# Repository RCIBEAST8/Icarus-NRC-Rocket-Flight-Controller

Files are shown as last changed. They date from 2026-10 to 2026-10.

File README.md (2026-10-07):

# Icarus - NRC Rocket Flight Controller

This is the avionics for **Icarus**, our entry to the UKSEDS National Rocketry
Championship at Coventry University. I was avionics lead on the team, so what's
in here is the flight computer, the airbrake control code that runs on it, and
the CFD I ran to get the drag numbers that code depends on.

The servo wiggle test running on the bench. It's in `setup()`, so on every power
up the brakes get driven fully open then fully closed before the thing arms. Cheap
way to confirm the servo's actually connected and the linkage is free before you
put it on a rail:

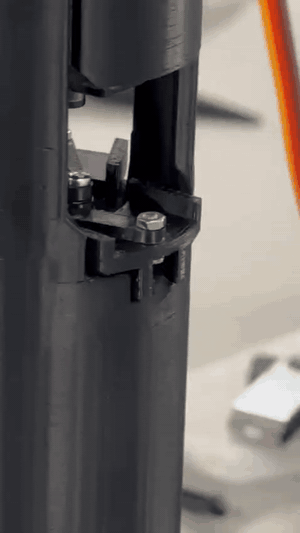
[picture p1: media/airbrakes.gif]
Airbrakes deploying


Full quality version with sound is at
[`media/airbrakes-deployment.mp4`](media/airbrakes-deployment.mp4).

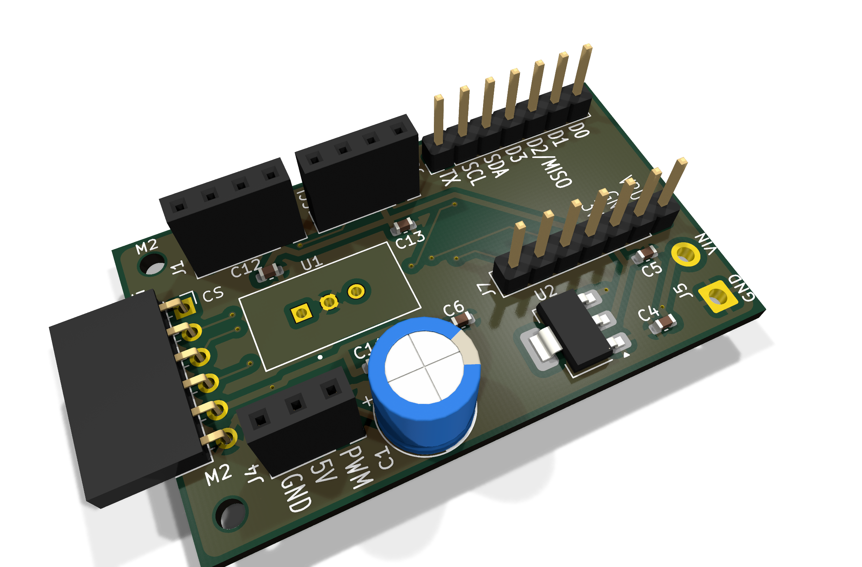
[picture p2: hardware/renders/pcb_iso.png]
Icarus avionics board


## It hasn't flown yet

We withdrew on competition launch day after problems turned up in pre-flight
checks. There's an independent flight test booked to the same parameters.

So everything in this repo is CFD, simulation or bench testing. None of it is
flight validated and it should be read that way.

## The rocket

| | |
|---|---|
| Length | 747.0 mm |
| Body diameter | 50.0 mm |
| Fineness ratio | 14.9 calibers |
| Nose cone | tangent ogive, 117.5 mm (2.35 cal) |
| Fins | 3 at 30 / 150 / 270 deg, 55.0 mm semi-span |
| Airbrakes | 3 blades at 90 / 210 / 330 deg, 12.7 mm proud when deployed |
| Wetted area | 0.1330 m^2 |
| Mass wet / dry | 0.789 kg / 0.7293 kg |
| Motor | AeroTech G78G-7, 109.9 Ns, 1.4 s burn |
| Recovery | separate EggTimer Apogee altimeter |
| Predicted apogee | 563-614 m across the saved OpenRocket runs, 122-125 m/s |

We pull the motor's ejection charge before flight. Recovery runs entirely off a
separate EggTimer Apogee board, so nothing in this repo can drop the parachute
and nothing in this repo can stop it dropping either. That was deliberate. I
didn't want the thing I wrote to be able to lose the rocket.

## What the flight computer does

A Seeed XIAO ESP32-C3 runs a 50 Hz loop, reads an ICM-20948 IMU and a BMP390
barometer, works out altitude and vertical velocity, and drives one servo that
sets how far the airbrakes are out. The point is to hit a target apogee by
dumping the extra energy as drag instead of coasting past it.

Every 20 ms cycle, once the motor's done burning, it:

1. sweeps 41 candidate drag coefficients between `CDClean` and `CDMax`
2. predicts what apogee each one gets you
3. picks whichever lands nearest the 560 m target, with overshoot punished 1.25x
   harder than undershoot (you can always add more drag later, you can never
   take it back)
4. maps that Cd to a servo angle, limited to 3 deg per step

The apogee prediction is a closed form solution rather than a numerical
integration. It comes from `m*dv/dt = -mg - 0.5*rho*Cd*A*v^2`, swapping time for
height, which gives:

```
h = (1/2k) * ln(1 + k*v0^2/g)      where k = rho*Cd*A/(2m)
```

I solve it twice, second pass with the density corrected for the altitude the
first pass says it's going to reach.

That choice matters on this chip. The ESP32-C3 has no hardware FPU, so every
float op is emulated in software. Doing 41 Euler integrations at 50 Hz was never
going to fit. Evaluating a log 41 times does.

### Being honest about the real-time side

This is soft real-time. The loop is a polled timer check inside `loop()`, not a
timer ISR and not a released RTOS task. I have not measured a worst case
execution time and there's no deadline miss detection. SD writes go through a
FreeRTOS queue so card latency can't stall the loop, but that's mitigation, not
a guarantee. I'd rather say that than pretend otherwise.

## Where the drag numbers come from

The controller is only as good as the drag model behind it, so I measured both
ends of it instead of guessing. Two OpenFOAM cases, same mesh and same reference
conditions, only difference being whether the brakes are out:

| Config | Case | Mean Cd | Constant in the firmware |
|---|---|---|---|
| brakes retracted | `cfd/clean/` | 0.472380 | `CDClean = 0.4724` |
| brakes deployed | `cfd/deployed/` | 0.877589 | `CDMax = 0.8776` |

Same mesh, same everything, brakes stowed and brakes out. Rail buttons are on
this side so you can see they're in both, the blades are the only thing that
changes between the two runs:

**Brakes stowed** (`cfd/clean`, Cd 0.4724)

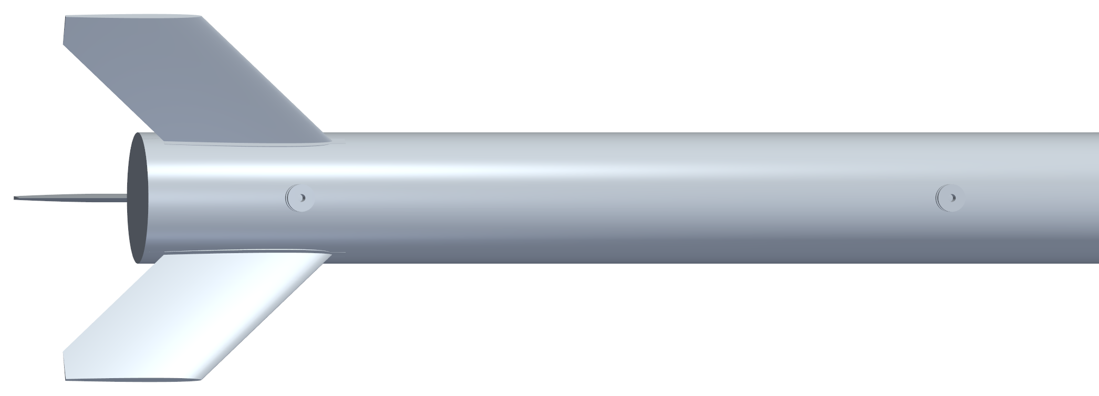
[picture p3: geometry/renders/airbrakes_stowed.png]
Airbrakes stowed


**Brakes deployed** (`cfd/deployed`, Cd 0.8776)

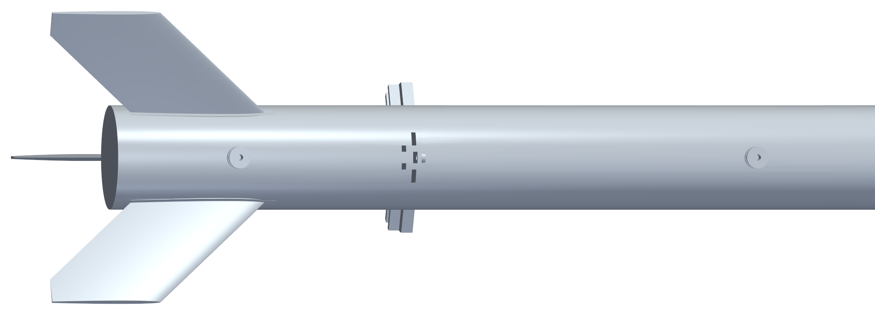
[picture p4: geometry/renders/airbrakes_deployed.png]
Airbrakes deployed


Putting the brakes out is worth 86% more drag. Both numbers are referenced to
the body cross section, `Aref = 0.0019635 m^2` (r = 25 mm), which is the same
value hardcoded in the firmware. That's on purpose, so the CFD and the onboard
prediction can't drift apart.

One thing that catches people out: the total projected frontal area with the
brakes deployed (body plus blades plus fins plus rail buttons) is about
0.00340 m^2, roughly 1.73x the reference area. That's a property of the shape,
not a reference area, and it isn't what any Cd in here is referenced to. Multiply
my coefficients by it and you'll overstate drag by 73%.

## What's in here

`firmware/` has the flight code and a software in the loop sim harness.
`hardware/` has renders of the board. `cfd/` has the OpenFOAM case setups, the
drag results for both configs and renders of the flow field. `simulation/` has
the OpenRocket model, the motor curve and a MATLAB script for reading flight
logs. `geometry/` has the STL the CFD was run against. `media/` has the bench
test footage.

### On the board

Renders only. I'm not publishing the schematic, layout, netlist or anything you
could send to a fab. The board's there to show what I built, not to be copied.
Ask me if you need more than that.

The customer payload we carried for the competition isn't in here at all. That
spec isn't mine to publish.

## Attribution

See [NOTICE.md](NOTICE.md). Icarus was a team vehicle and this repo only covers
my part of it.

There's no licence file, which means all rights reserved. Ask before reusing
anything.

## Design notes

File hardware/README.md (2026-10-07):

# Hardware

Isometric

Renders only. The schematic, layout, netlist and fabrication outputs (Gerbers,
drill files, pick and place) are deliberately not published and are blocked in
`.gitignore`. The board's here to show what I built, not for anyone to send off
to a fab. Ask me if you need more detail than this.

It's a 50.0 x 30.0 mm two layer board. The XIAO ESP32-C3 sits at `U1` and
basically everything else on there exists to power it, break its buses out, and
keep it alive while a servo shares the same supply.

| Ref | What it is |
|---|---|
| `U1` | Seeed XIAO ESP32-C3 module footprint |
| `U2` | SOT-223 linear regulator, with `C4` / `C5` either side of it |
| `C1` | bulk electrolytic, sat right next to the servo header |
| `J1`, `J2` | two I2C breakouts (SCL, SDA, 3V3, GND) for the IMU and the baro |
| `J3` | SPI header for the microSD, with CS broken out |
| `J4` | servo (GND, 5V, PWM) |
| `J7`, `J8` | XIAO headers, VBUS/3V3/GND one side, D0-D3/TX/SDA/SCL the other |
| `VIN`, `GND` | power in |
| `M2` x2 | mounting holes |

The bulk cap next to `J4` is there on purpose. A servo under stall load pulls
current in sharp bursts and without local bulk capacitance those transients drag
the rail down far enough to brown out the microcontroller mid flight. The IMU and
baro also get their own separate I2C headers rather than being daisy chained, so
each one gets a short run.

There are four renders in `renders/`: an isometric and a flat top down
(`pcb_iso.png`, `pcb_top.png`), plus the same two from underneath
(`pcb_iso_bottom.png`, `pcb_bottom.png`). The flat top down is the useful one if
you want to read the silkscreen and follow the routing.

They're generated out of the KiCad 10 project with `kicad-cli pcb render`. `U1`
and `J3` show up as plain outlines because those footprints don't have 3D models
attached, so the XIAO itself isn't shown sitting in its socket.

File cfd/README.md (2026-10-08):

# CFD

Two OpenFOAM cases over the same mesh and the same reference conditions. The only
thing that changes between them is whether the airbrakes are out. These two runs
are where the controller's drag model comes from.

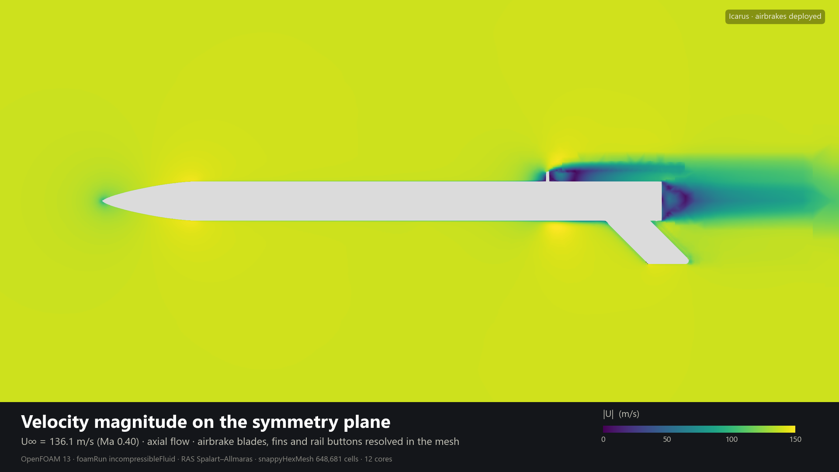
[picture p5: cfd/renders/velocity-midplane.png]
Velocity magnitude on the symmetry plane, airbrakes deployed


| Case | Brakes | Mean Cd | Firmware constant |
|---|---|---|---|
| `clean/` | retracted | 0.472380 | `CDClean = 0.4724` |
| `deployed/` | deployed | 0.877589 | `CDMax = 0.8776` |

86% more drag with the brakes out. Mean Cd is averaged over 0.025-0.050 s, after
the force history has settled down. `rangeCD.dat` in each case has the standard
deviation and the min/max over that window if you want to see how steady it was.

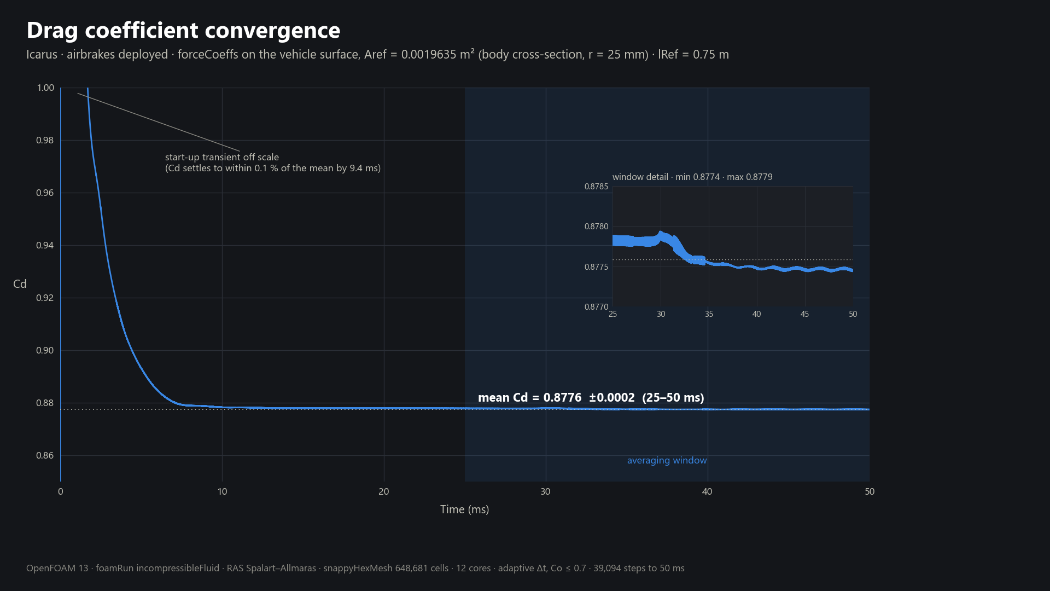
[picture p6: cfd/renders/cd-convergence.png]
Drag coefficient convergence, deployed case


Cd is inside 0.1% of its own mean by 9.4 ms and the whole averaging window fits in
±0.0002, so the number isn't sensitive to where I put the window.

Every picture on this page is the deployed run at the final time, 0.05 s.

## Setup

| | |
|---|---|
| Solver | OpenFOAM 13, `foamRun` |
| Turbulence | RAS, Spalart-Allmaras |
| Freestream | 136.1 m/s, which is Mach 0.40 |
| Density | 1.225 kg/m^3 |
| Kinematic viscosity | 1.5e-5 m^2/s |
| Reynolds number | about 6.8e6 on lRef = 0.75 m |
| Reference area | 0.0019635 m^2, body cross section at r = 25 mm |
| Reference length | 0.75 m |
| Time stepping | adjustable, max Courant 0.7, ends at 0.05 s |

`Aref` is the body cross section. It is not the total projected frontal area of
the deployed config (that's about 0.00340 m^2, 1.73x bigger). The firmware uses
the same 0.0019635, so the CFD and what the rocket thinks are always the same
number.

## What the flow looks like

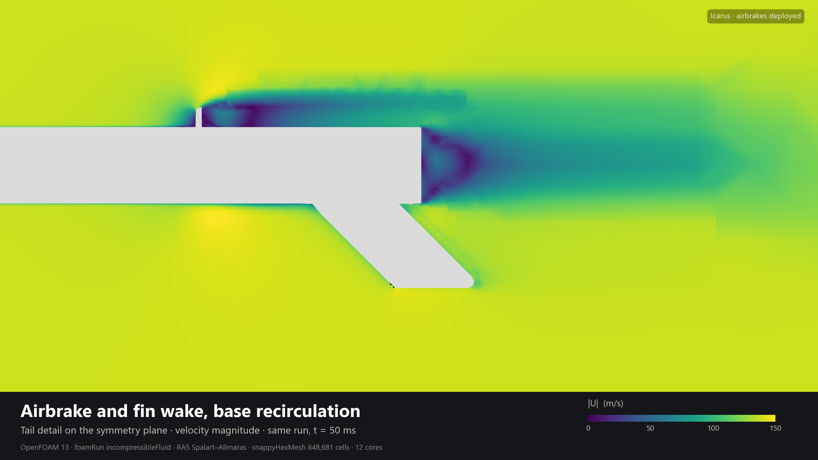
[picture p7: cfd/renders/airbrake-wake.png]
Airbrake and fin wake, base recirculation


The blades sit just ahead of the fins and throw a thick low speed wake straight
down the fin span. The flat base is doing its own share behind that, with the
recirculation sitting in the middle of it.

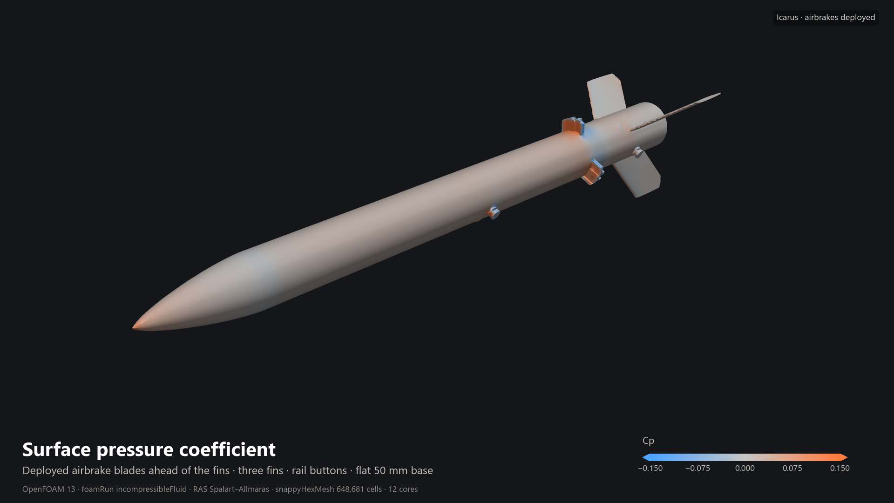
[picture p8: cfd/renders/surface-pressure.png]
Surface pressure coefficient


Cp on the skin. High pressure on the nose and on the leading face of each blade,
suction immediately behind them, and the rail buttons showing up as their own
little pressure spots. The scale is clipped at ±0.15 so the nose saturates, real
stagnation Cp there is about 1.

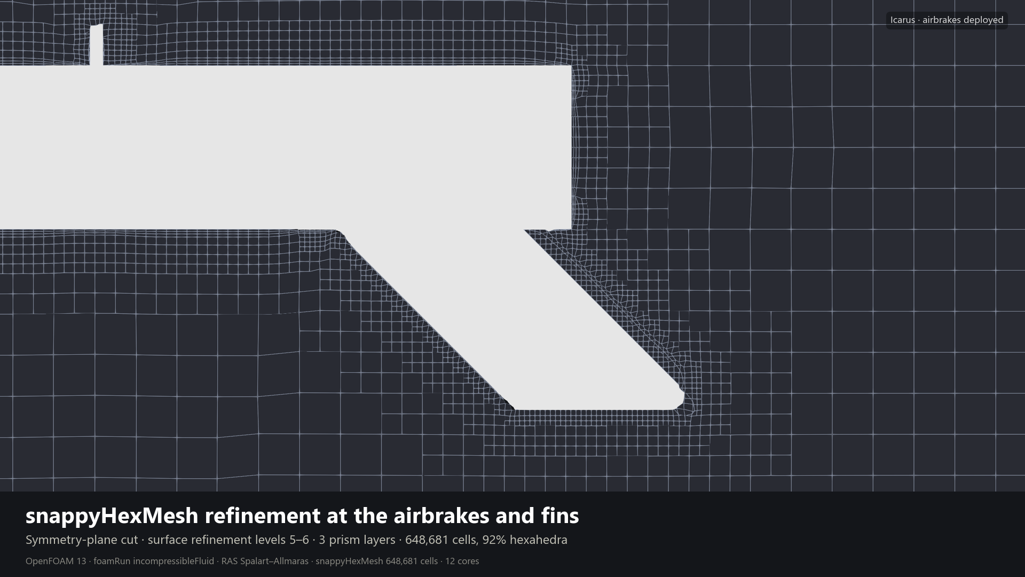
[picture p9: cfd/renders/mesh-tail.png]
snappyHexMesh refinement at the airbrakes and fins


The mesh around the tail. Surface refinement levels 5-6, 3 prism layers, 648,681
cells with 92% of them hexahedra. `checkMesh` flagged 8 highly skewed faces, so
it isn't a clean pass.

## Where these numbers are weak

Worth being straight about, because it tells you how far to trust them.

The solver is incompressible and I'm running it at Mach 0.40. The usual rule of
thumb is incompressible holds to about Mach 0.3. At 0.40 the real density
variation over the vehicle is something like 8%, so treat these as a solid
engineering estimate rather than a converged compressible answer.

The airbrake blades are modelled as detached plates. In the mesh the radius jumps
from 25.0 to 33.4 mm with an 8.4 mm gap, and there's no linkage or slot geometry
in there at all.

The back end is a flat 50 mm disc. No nozzle, no boat tail. Base drag is doing
real work in the clean number because of that.

Axial flow only, one angle of attack. No yaw or pitch sweep.

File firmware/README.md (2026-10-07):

# Firmware

`XIAO_ESP32-C3_CODE.ino` is the flight code. `Xiao_sim_test.ino` is the same
controller wired to a synthetic flight so I can test it without burning a motor.

## Hardware it runs on

Seeed XIAO ESP32-C3 (RV32IMC). No hardware FPU, so every float operation is
emulated in software. That's the single biggest constraint on what fits in the
loop budget and it's why the apogee predictor is a closed form solution.

| Part | Bus | Notes |
|---|---|---|
| ICM-20948 | I2C | 9 axis IMU |
| BMP390 | I2C | barometer, this is the primary altitude source |
| microSD | SPI | logging, behind a FreeRTOS queue |
| airbrake servo | PWM | 0-126 deg, 126 is a mechanical limit on the linkage |

Loop runs at 20 ms (50 Hz). Barometric velocity is filtered down to 10 Hz on
purpose, slower than the loop, so the estimator isn't chasing sensor noise.

MISO isn't on the usual pin, because of boot state issues on the XIAO.

## States

`PAD_IDLE` -> `ASCENT` -> `DESCENT` -> `LANDED`

Launch detect fires on integrated IMU distance >= 1.0 m or altitude >= 50 m AGL.
That pad integration (`currentvelocity`) is only used to spot the launch and to
seed the in-flight estimate, it gets thrown away after that because it drifts.

In flight the accelerometer propagates velocity every 20 ms tick and the
barometer corrects it, pulling the estimate 35% of the way toward the alpha-beta
baro velocity each 10 Hz update. During the burn that correction is switched off
completely, so for the first 1.4 s it's running on the accelerometer alone.

Apogee detect needs peak altitude above 50 m first, then fires on fused velocity
< -2.0 m/s or 5 falling samples in a row. Landing detect wants to be below 25 m
AGL with altitude stable within 3 m and acceleration within 1.5 m/s^2 of 1 g,
held for 5 seconds.

Brakes stay stowed until burn time + 0.1 s, then the controller arms. That delay
is there to stop the servo straining against itself. Three seconds after apogee
they get driven fully open to add drag on the way down.

## Constants worth knowing

| Constant | Value | What it is |
|---|---|---|
| `alpha` / `beta` | 0.4 / 0.05 | alpha-beta filter gains on baro altitude |
| `BARO_TRUST` | 0.35 | how much of the baro/inertial gap gets corrected each tick |
| `area` | 0.0019635 m^2 | CFD reference area, has to match the CFD |
| `CDClean` / `CDMax` | 0.4724 / 0.8776 | straight out of `cfd/clean` and `cfd/deployed` |
| `apogeeTgt` | 560 m | target apogee (about 1840 ft) |
| `overshootPenalty` | 1.25 | makes the controller prefer undershooting |
| `MPC_CANDIDATES` | 41 | how many drag values it tries per cycle |

`padMass` is the wet mass at 0.789 kg, `dryMass` is 0.7293 kg. Through the burn
the mass is interpolated linearly between the two on elapsed time, then held at
dry mass after burnout. A straight line isn't the real burn profile, but the burn
is 1.4 s and the MPC doesn't arm until 0.1 s after it, so in practice the
controller only ever sees dry mass anyway.

## Real-time classification

Soft real-time. It's a polled periodic trigger in `loop()`, not a timer ISR and
not a released RTOS task. No measured worst case execution time, no deadline miss
detection. SD writes are queued so they can't stall the loop.

Guards that are in there: density clamped to 0.6-1.4 kg/m^3, velocity clamped to
-150 to 200 m/s, barometric altitude rejected outside -500 to 10000 m, a divide
by zero guard on the drag term, servo rate limiting and a 5 degree deadband.

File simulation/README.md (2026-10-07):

# Simulation

`NRC_Rocket.ork` is the OpenRocket model, `AeroTech_G78G.eng` is the motor curve,
and `ICARUS_Flight_Data_Logger_v2.m` is the MATLAB script I use to read flight
and sim logs back.

## What OpenRocket predicts

The model holds several saved runs. They land between 562.7 m and 613.7 m
apogee, with max velocity between 121.6 and 124.5 m/s.

Those are clean numbers, brakes stowed the whole way up. The flight code targets
560 m, which sits under every run here, so the controller always has something to
trim off. The slowest run only clears the target by about 3 m though, so that's
the case worth re-running when the model gets updated.

## Motor, AeroTech G78G-7

| | |
|---|---|
| Total impulse | 109.9 Ns |
| Peak / average thrust | 101.9 N / 78 N |
| Burn time | 1.4 s |
| Propellant / total mass | 59.7 g / 125.0 g |
| Size | 29 x 146 mm |
| Delay | 7 s |

Don't swap in the ThrustCurve "G78G/L" RASP file. It's a different variant
(133.2 Ns, 1.7 s burn, 128 mm long) and it does not match this motor. It'll run
fine and quietly give you the wrong trajectory, which is worse than it failing.
The curve in here is modelled off published AeroTech / Apogee data and hits total
impulse, peak and mean to inside 0.1%.

The 7 second ejection delay doesn't get used. We take the ejection charge out
before flight and recovery is triggered by a separate EggTimer Apogee altimeter,
so the flight code ignores motor driven deployment completely.

## Reading logs back

`ICARUS_Flight_Data_Logger_v2.m` pulls the SD log in and plots altitude,
velocity, servo angle, the Cd the controller asked for and what apogee it was
predicting at the time. v2 works out the column count from the header instead of
hardcoding it, so it takes both the 18 column real flight log and the 20 column
sim log (the sim one carries `TrueAlt` and `TrueVel` ground truth out of
`Xiao_sim_test`).

Set `CFG.file` to point it at something, or just drop it in a folder full of CSVs
and it grabs the newest one.

Check `CFG.targetApogee` before you read anything into a plot. It defaults to
530 m and the flight firmware now targets 560 m, so if they don't match the error
traces will look wrong.

One that's easy to get backwards: 126 degrees is stowed (minimum drag) and 0 is
fully open (maximum drag).

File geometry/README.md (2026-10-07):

# Geometry

`SRocketMesh.stl` is the deployed airbrake outer skin and it's the exact surface
the CFD in [`../cfd/`](../cfd/) ran against.

24,810 triangles, roughly 3.3 mm mean edge length, one `zone0` solid, units in
metres.

## The two configurations

Both meshes rendered from the same camera, viewed from the side the rail buttons
are on. Brakes stowed first, then deployed.

Airbrakes stowed

Airbrakes deployed

Closer in on the blade station, same pair:

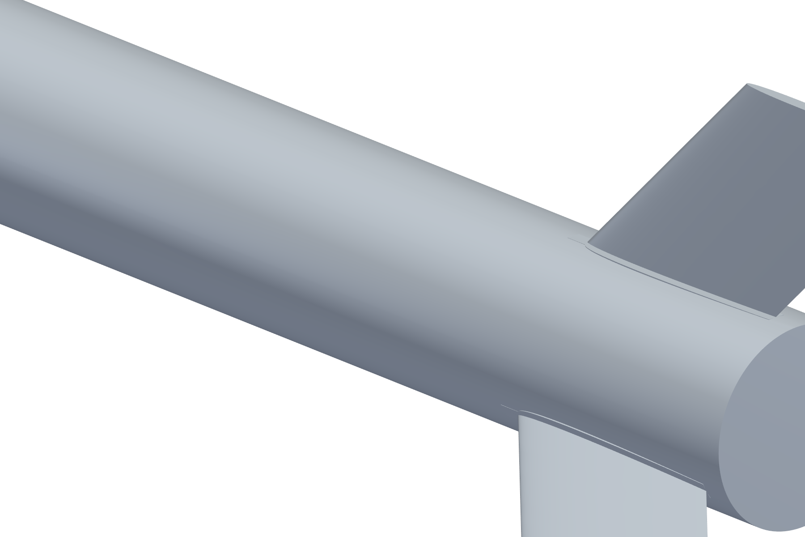
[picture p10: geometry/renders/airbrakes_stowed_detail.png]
Airbrakes stowed, detail


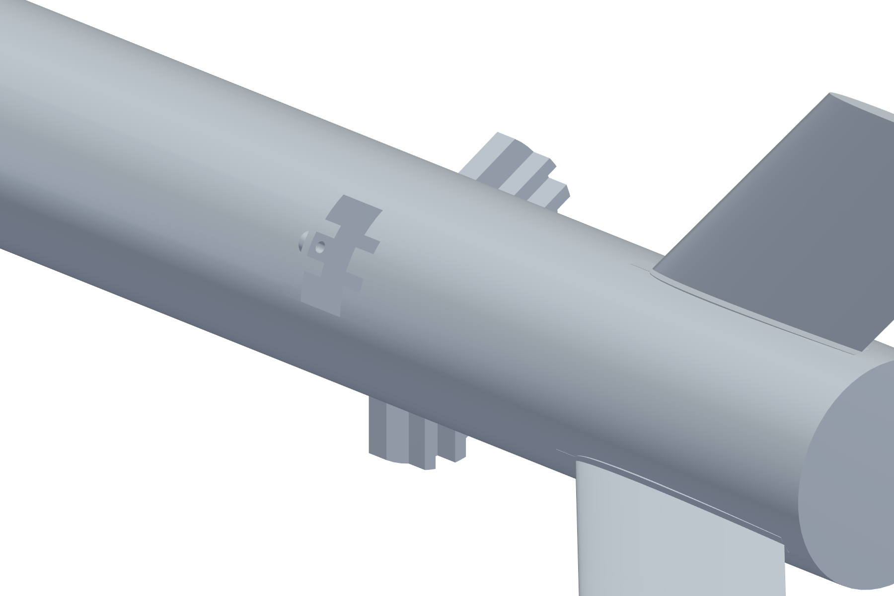
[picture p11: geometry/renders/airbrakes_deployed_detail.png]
Airbrakes deployed, detail


I checked the two meshes actually match everywhere else before running them.
Walking the radius along the body they're identical, including the rail buttons
at r = 31.93 mm, and the only station that differs is x = -160 to -120 mm where
the deployed mesh goes out to r = 37.69 mm and the clean one stays at 25.00 mm.
So the difference in Cd between the two runs is the airbrakes and nothing else.

## Measured dimensions

I took these off the STL itself rather than out of CAD, so they're what the
solver actually saw rather than what the model was supposed to be.

| | |
|---|---|
| Overall length | 747.0 mm |
| Body diameter | 50.0 mm (r = 25.0) |
| Fineness ratio | 14.9 calibers |
| Nose cone | tangent ogive, 117.5 mm (2.35 cal), fits to about 1 mm |
| Parallel body | x = 117.5 to 640.5 mm (523 mm) |
| Fins | 3, at 30 / 150 / 270 deg |
| Fin root / tip chord | 106.5 mm / 53.8 mm |
| Fin semi-span | 55.0 mm from the wall, 160 mm tip to tip (3.2 cal) |
| Fin LE sweep | about 44.5 deg |
| Fin section | tapered, 3.25 mm max thickness, 0.6 mm at the TE |
| Airbrakes | 3 blades at 90 / 210 / 330 deg, interleaved between the fins |
| Blade station | x = 564.5-575.0 mm, 10.5 mm streamwise |
| Blade arc | 38.2 deg each, so 114.6 deg total, about 32% of the circumference |
| Blade deployment | outer face at r = 37.7 mm, 12.7 mm proud of the body |
| Rail buttons | 2 at 210 deg, 10.5 mm long, 6.9 mm proud, x = 398 and 649 mm |
| Wetted area | 0.1330 m^2 |
| Enclosed volume | 1.31 L |

## Two different areas, don't mix them

There are two frontal areas floating around for this rocket and they are not
interchangeable.

The body reference area is 0.0019635 m^2. That's what every Cd in this repo is
referenced to and it's the `area` constant in the flight firmware.

The total projected frontal area with the brakes out is about 0.00340 m^2. That's
body plus blades plus fins plus rail buttons and it's 1.73x the first number.
It's a description of the shape, not a reference area. Multiply my coefficients
by it and you overstate drag by 73%.

## Simplifications in this mesh

The airbrake blades are detached plates. The radius jumps 25.0 to 33.4 mm with an
8.4 mm void and there's no linkage or slot modelled.

The aft end is a flat 50 mm disc, no nozzle and no boat tail, so base drag is
carrying real weight in the clean coefficient.

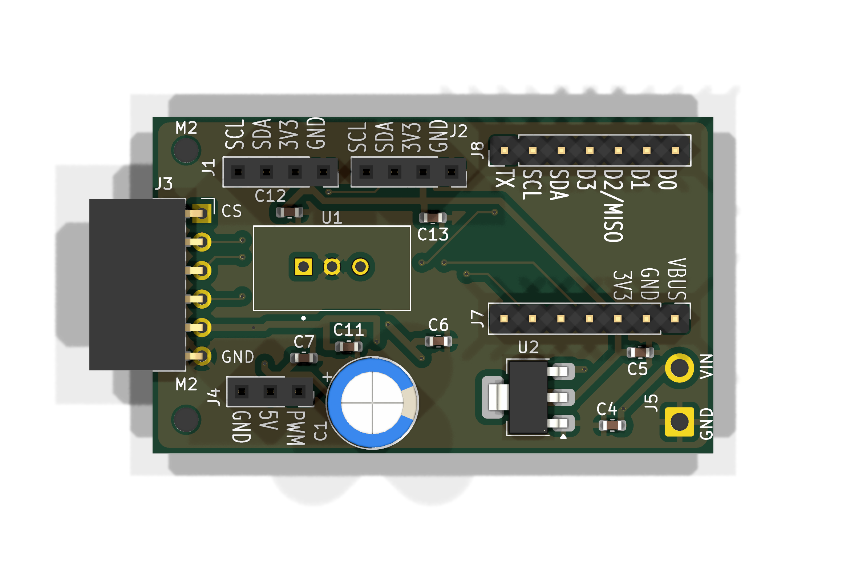
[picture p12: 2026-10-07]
hardware/renders/pcb_top.png

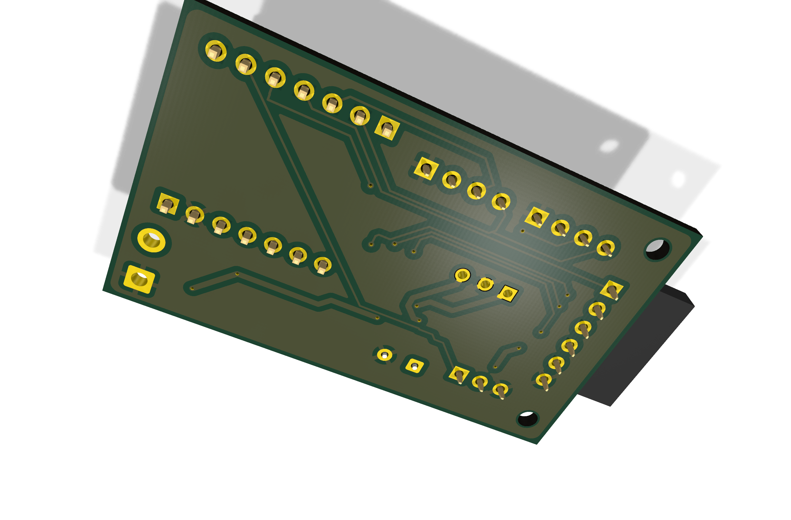
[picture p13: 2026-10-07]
hardware/renders/pcb_iso_bottom.png

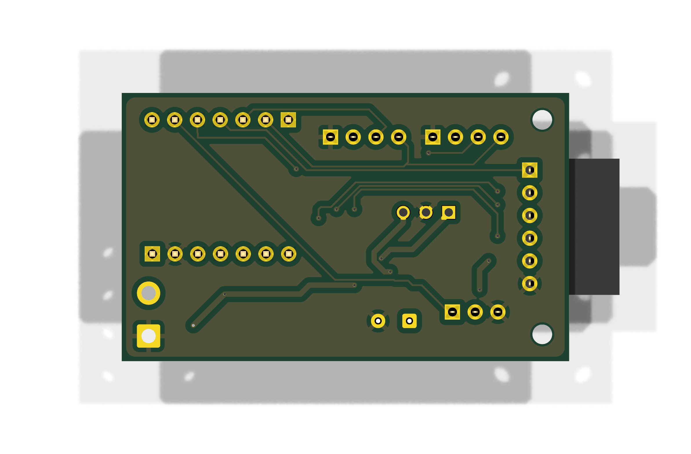
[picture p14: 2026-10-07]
hardware/renders/pcb_bottom.png

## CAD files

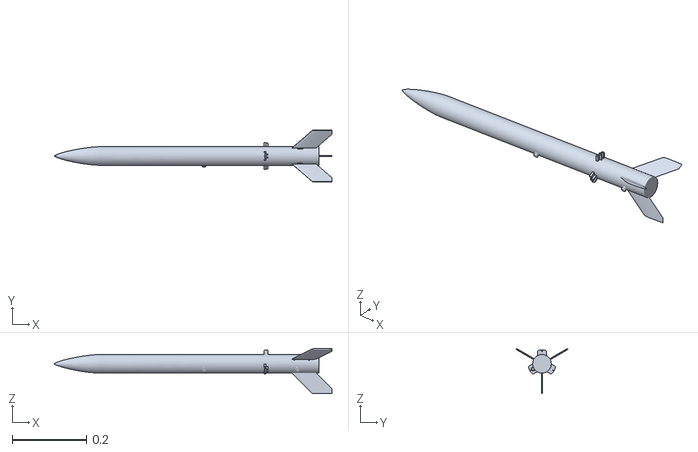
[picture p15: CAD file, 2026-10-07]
geometry/SRocketMesh.stl
0.747 x 0.14 x 0.121

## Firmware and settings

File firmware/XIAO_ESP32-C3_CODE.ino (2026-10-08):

// for xiao esp32-c3  (no FPU so thats why there is "f" on most values)
// Icarus rocket
// mpc controller

//code breakdown
//sensor logger for icm-20948 and bmp390 sensors which writes data onto an sd card in CSV format so easy to graph.
//active aero sim to slow down the rocket to reach target apogee. active aero sim controls servo motor for the airbrakes.

//libs
#include <SPI.h>
#include <SD.h>
#include <Wire.h>
#include <Adafruit_Sensor.h>
#include <Adafruit_BMP3XX.h>
#include <Adafruit_ICM20X.h>
#include <Adafruit_ICM20948.h>
#include <ESP32Servo.h>


#define SEALEVELPRESSURE_PA (101325.0) //sea level in pascals
#define BMP_PRESSURE_IS_PA 1 // 1 means pa // 0 means hpa

// SPI linking 
const int chipSelect = D3;
const int SD_SCK  = D8;
const int SD_MISO = D2;  // not the normal MISO pin, the default one messes with boot on the xiao and drops it into sleep states
const int SD_MOSI = D10;

//sensor objects
Adafruit_BMP3XX bmp;
Adafruit_ICM20948 icm;
Servo myservo;

//  data logging object
File dataFile;

// creating a ram buffer to compile before writing // 256bytes x 100 depth = 25.6KB of SRAM out of 400 total
QueueHandle_t sdQueue;
TaskHandle_t sdTaskHandle;
#define LOG_BUF_LEN   256     //ram buffer 
#define LOG_QUEUE_LEN 100     //queue depth
char logBuffer[LOG_BUF_LEN];
bool loggingEnabled = true;

// better than delays logs at 50hz (20ms)
unsigned long previousMicros = 0;
const unsigned long INTERVAL_US = 20000UL; //20ms
unsigned long loopDtUs = 0;

//rocket airbreak master controller
enum FlightState
{
  PAD_IDLE,
  ASCENT,
  DESCENT,
  LANDED
};
FlightState currentState = PAD_IDLE;

//altitude variables
float groundAltitude = 0.0;
float currentAltitude = 0.0;
float previousAltitude = 0.0;
unsigned long previousTime = 0;

// distance and velocity tracking for code starter. code is gonna kick in a 1m as the rocket will reach that after 140ms with roughly 101m/s (acceleration) off launch.
//starting code
float currentvelocity = 0.0;     // used only on pad not in air (drifts values alot)
float barovelocity = 0.0;
float distancetravelled = 0.0;
float predictedVel = 0.0;
float baroAccel = 0.0;
float alpha = 0.4;                // controls how strongly the barometer measurements corrects velocity estimates // higher the number higher the noise but faster tracking
float beta = 0.05;                // similar to above but extremely noise so set very low 
float fusedVelocity = 0.0;        // the velocity the mpc uses as the baro is filtered at 10hz in code even though the sensor runs at 50hz, im making it purposely lower
const float BARO_TRUST = 0.35;    // how hard each baro tick corrects the fusion // 0.35 means 35% of the gap on every tick basically enough to stop accelerometer drift

//sanity clamps for BMP
const float RHO_MIN = 0.6;
const float RHO_MAX = 1.4;
const float VEL_MIN = -150.0;
const float VEL_MAX = 200.0; // real max vel is ~116m/s so 85m/s of headroom 

//backup apogee detection
int fallingCount = 0; //back up incase velocity estimate is wack
float peakAltitude = 0.0; // logs highest altitude reach at all times

//landing detection and health check
unsigned long stillSince =0;
volatile bool closeRequested = false;
unsigned int droppedLogs = 0;
unsigned int missedBaro = 0;

//referance altitude and brands for landing detector
float landingRefAlt = 0.0;
const float LANDING_ALT_MAX  = 25.0;   // max altitude from pad altitude which landing could happen at. pad is roughly 103m from sealevel so max would be +128m and -78m more than big enough headroom
const float LANDING_ALT_BAND = 3.0;    // altitude must not move more than this
const float LANDING_ACC_BAND = 1.5;    // |a| must be within this of 1g

// REAL TIME MASS CALC
unsigned long launchTime = 0;           // total launch time from burn start
float dryMass = 0.7293;                 // DRY MASS WEIGHT
float padMass = 0.789;                  // WET MASS 
float currentMass = padMass;
float burnTime = 1.4;                   //1.4s rocket burn // G78G-7 aerotech rocket motor 

//servo controller
int currentServoAngle = 126;    // tracks servo degrees
const int SERVO_MIN = 0;        // hard lower limit // open = max drag
const int SERVO_MAX = 126;      // hard upper limit // closed = least drag
const int SERVO_STEP = 3;       // maximum degrees per step
const int SERVO_DEADBAND = 5;   // ignores any movements under 5 degrees 

//mpc varibles 
float area = 0.0019635;                  // cfd referenace area 
float rho = 1.225;                       // density of air (1.225kg/m^3)
float CDClean = 0.4724;                  // airbrakes retracted //validated by my CFD
float CDMax   = 0.8776;                  // airbrakes deployed  //validated by my CFD
float CD = CDClean;                      // mpc starts clean each run
int apogeeTgt = 560;                     //apoge target in metres (560m = 1837 feet) (580m = 1902 feet) (600m = 1968 feet)
const float overshootPenalty = 1.25;     // tells the mpc to aim for slight undershoot rather than extreme overshoot
const float MPC_ARM_MARGIN_S = 0.1;      // 0.1s delay before servo is aloud to move after burn phase so it doesnt strain itself, might change to 0.3seconds

//apogee airbrake controller
const unsigned long AIRBRAKE_DESCENT_DELAY_MS = 3000UL; // 3 second delay after apogee to max airbrakes
unsigned long apogeeTime = 0;
bool brakesDeployed = false; // check airbrake state

// MPC stuff
#define MPC_CANDIDATES 41  // amount of simsulations
float bestApogee = 0.0;    //what the winning candidate predicted 

// accelerometer scale correction 
float accelScale = 1.0f;

//tells compiler to run the SD background tasks
void logToSDTask(void *pvParameters);

// makes sure everything is done in pascals 
float pressurePa()
{
#if BMP_PRESSURE_IS_PA
  return bmp.pressure;
#else
  return bmp.pressure * 100.0;
#endif
}

//altitude checker
float altitudeFromPa()
{
  return 44330.0f * (1.0f - powf(pressurePa() / (float)SEALEVELPRESSURE_PA, 0.1903f)); //barometric formula but inverted for height
}

// density checker
float airDensity()
{
  return pressurePa() / (287.05f * (bmp.temperature + 273.15f));  // ideal gas law rearranged 
}

//                                       apogee predictor                                            // 

// sim predicts what do with the brakes based on the logic of if i slammed the brakes now and coast what would my apogee be
// sim comes from:        m·dv/dt = -mg - ½·ρ·Cd·A·v²       which goes to       v·dv/dh = -g - k·v²        where k = ρ·Cd·A/(2m) where time is swapped for height using   v·dv/dh = dv/dt
float predictApogee(float cdSim, float alt0, float v0, float mass)
{
  if (v0 <= 0.0f) return alt0;                                            // checks how much the rocket will climb at current speed, (also techincally kills the sim at apogee where velocity becomes negative along Y axis)
  float k = (rho * cdSim * area) / (2.0f * mass);                         // bundles the whole drag setup into one number
  if (k < 1e-9f) return alt0;                                             // divide-by-zero guard (would of put a NaN but it woulda killed it)
  float h = (1.0f / (2.0f * k)) * logf(1.0f + (k * v0 * v0) / 9.81f);     // sim output (how much higher the rocket will climb until apogee (velcoity =0))
  float rhoMid = rho * (1.0f - (0.5f * h) / 8500.0f);                     // redo sim but with decaying density (air thinner not by much but mayaswell)
  if (rhoMid < RHO_MIN) rhoMid = RHO_MIN;                                 // stops a insane H value given (basically if h was too big it would turn rhoMid negative basically saying neagtive density which means negative drag so bad)

 // redoes the sim part with the new density (more accurate density)
  k = (rhoMid * cdSim * area) / (2.0f * mass); 
  if (k < 1e-9f) return alt0;
  h = (1.0f / (2.0f * k)) * logf(1.0f + (k * v0 * v0) / 9.81f);
  return alt0 + h;                                                        // coast height (h) added to curent altitude (predicted apogee)

}

//                                      main setup                                  //
void setup()
{
  // setting up SD card
  Serial.begin(115200); //115200 baud rate
  Serial.setTxTimeoutMs(0); // doesnt block the loop if not device is attached
  Serial.println("initialising");
  delay (2000); // safety net

  // Creates the queue in RAM and launches the background SD logger.
  //also kills logging if queue crashes so it doesnt kill the entire code
  sdQueue = xQueueCreate(LOG_QUEUE_LEN, sizeof(logBuffer));
  if (sdQueue == NULL)
  {
    Serial.println("QUEUE ALLOCATION FAILED - SD logging disabled");
    loggingEnabled = false;
  }
  xTaskCreate(
    logToSDTask,   //task function
    "SD_Task",     //name
    4096,          //stack size
    NULL,          //parameters
    1,             //priority
    &sdTaskHandle  //handle
  );

  //the xiao needs its own timers allocated before it'll write servos
  ESP32PWM::allocateTimer(0);
  ESP32PWM::allocateTimer(1);
  ESP32PWM::allocateTimer(2);
  ESP32PWM::allocateTimer(3);
  myservo.setPeriodHertz(50);
  myservo.attach(D1, 500, 2400); // servo pin is now D1


  //                    SERVO WIGGLE TEST                                         //
  Serial.println("performing servo wiggle test");
  myservo.write(SERVO_MIN); // 0 Degrees (Fully Open)
  delay(1000);
  myservo.write(SERVO_MAX); // 126 Degrees (Fully Closed)
  delay(1000);
  currentServoAngle = SERVO_MAX; // Ensure logic matches physical state
  Serial.println("Servo test complete now ready to launch");


  //cranking up the speed on i2c bus to 400kHz
  Wire.begin();
  Wire.setClock(400000);

  SPI.begin(SD_SCK, SD_MISO, SD_MOSI, chipSelect); //forcing spi pins

  if (!SD.begin(chipSelect, SPI, 4000000)) // checks SD card is working and kills logging if its fails so doesnt kill code
  {
    Serial.println("SD Card Failed - CONTINUING WITHOUT LOGGING");
    loggingEnabled = false;
  }

  Serial.println("Initializing BMP390 Sensor");
  if (!bmp.begin_I2C())
  {
    Serial.println("BMP390 Failed to initialize");
    while(1) { vTaskDelay(pdMS_TO_TICKS(100)); } //properly block BMP390 if it fail fails (better than yield)
  }


  // built in filtering and oversampling + preflight checker 
  if (!bmp.setTemperatureOversampling(BMP3_OVERSAMPLING_2X)) Serial.println("WARNING: temp OSR rejected");
  if (!bmp.setPressureOversampling(BMP3_OVERSAMPLING_4X))    Serial.println("WARNING: press OSR rejected");
  if (!bmp.setIIRFilterCoeff(BMP3_IIR_FILTER_COEFF_3))       Serial.println("WARNING: IIR coeff rejected");
  if (!bmp.setOutputDataRate(BMP3_ODR_50_HZ))                Serial.println("WARNING: 50Hz ODR REJECTED - oversampling too high");


  // checking ICM-20948 sensor
  Serial.println("initializing TDK INVENSENSE ICM-20948");
  if (!icm.begin_I2C())
  {
    Serial.println("ICM-20948 Failed to initialize");
    while(1) { vTaskDelay(pdMS_TO_TICKS(100)); } // same reason as BMP 390
  }

  icm.setAccelRange(ICM20948_ACCEL_RANGE_16_G);    // sets IMU to +or- 16G / peak G should be 11G
  icm.setGyroRange(ICM20948_GYRO_RANGE_2000_DPS);  //sets IMU to max 2000 degrees of roll per a second

  // read ICM data 10 times to clear the buffer and also help it settle down to a stable state
  for (int i = 0; i < 10; i++)
  {
    sensors_event_t accel, gyro, temp, mag;
    icm.getEvent(&accel, &gyro, &temp, &mag);
    delay(50);
  }

  //BMP reads where it is compared to sea level to get ground level. im a genius BTW
  Serial.println("Calibrating Ground Altitude");
  float altSum = 0.0f;
  int   altN = 0;
  for (int i = 0; i < 20; i++)
  {
    if (bmp.performReading()) { altSum += altitudeFromPa(); altN++; }
    delay(50);
  }
  if (altN > 0) groundAltitude = altSum / (float)altN; // pad altitude (sets the baseline altitude as a referance for all new altitude readings)
  else
  {
    groundAltitude = altitudeFromPa();
    Serial.println("WARNING: no good baro reads during ground calibration - using last value");
  }
  Serial.print("ground alt samples used: "); Serial.println(altN);

  previousAltitude = groundAltitude; // checks if pad alt is correct and not nonsense 
  previousTime = millis();

  // sanity check before flight
  Serial.print("BMP pressure (Pa): "); Serial.println(pressurePa());
  Serial.print("pad air density: "); Serial.println(airDensity()); //check if it is 1.225 or not
  Serial.print("apogee target: "); Serial.println(apogeeTgt);

  // creating data file and writing
  dataFile = SD.open("/flight_data.csv", FILE_APPEND);
  if (dataFile)
  {
    dataFile.println("Time(ms),State,Alt,Vel,ServoAngle,Temp_C,Press_Pa,AccelX,AccelY,AccelZ,GyroX,GyroY,GyroZ,MagX,MagY,MagZ,CD,PredApogee"); // logging column headers
    dataFile.flush(); // flushes data to the other void code 
    Serial.println("sensors are logging, READY FOR LAUNCH GO GO GOOOOOOO");
  }
  else
  {
    Serial.println("Error starting file, check for corruption");
    loggingEnabled = false; // just incase it dies during flight or when the rocket is on the rail
  }

  delay(5000); //safety net
  previousMicros = micros();
  previousTime   = millis();
}

//                            main code                               //
void loop()
{
  // timing stuff for sim loops so if sd or mpc messes up this fixes it or prevents it
  unsigned long currentMicros = micros();
  if (currentMicros - previousMicros >= INTERVAL_US)
  {
    loopDtUs = currentMicros - previousMicros;
    float dt = (float)loopDtUs * 1e-6f; // delta T in seconds
    previousMicros = currentMicros;
    unsigned long currentMillis = millis();

    bool baroOk = true;
    if (!bmp.performReading()) // checks for missed bmp readings and replaces them with last good altitude reading
      {
        baroOk = false;
        missedBaro++;
      }
    else
    {
      float altNew = altitudeFromPa();
      if (altNew > -500.0f && altNew < 10000.0f) { currentAltitude = altNew; } //rejects non finite altitude so the code doesnt use it
      else { baroOk = false; missedBaro++; }
    }
    sensors_event_t accel, gyro, mag, temp;
    icm.getEvent(&accel, &gyro, &temp, &mag);

    //pad calibration
    float ax = accel.acceleration.x * accelScale; //accelx
    float ay = accel.acceleration.y * accelScale; //accely
    float az = accel.acceleration.z * accelScale; //accelz


    float agl = currentAltitude - groundAltitude; // height from the pad baseline reading

    // fused the imu filter with the built in nano filter
    if (currentState == PAD_IDLE)
    {
      //abs acceleration in all directions
       float accelMag = sqrtf(sq(ax) + sq(ay) + sq(az));
      // subtract 1G cus gravity
      float netAccel = accelMag - 9.81f;

      //filter to ignore anything less than (2m/s)^2 or 0.204G
      if (netAccel > 2.0f)
      {
        currentvelocity += netAccel * dt;
      }
      else
      {
        currentvelocity = 0.0f;
        distancetravelled = 0.0f;
      }

      // Always add velocity to distance. (If we are on the pad, velocity is 0, so distance stays 0).
      distancetravelled += currentvelocity * dt;


      //checks for ascent 
      if (distancetravelled >= 1.0f || agl >= 50.0f) // checks till 50m above pad
      {
        currentState = ASCENT;
        launchTime = (millis() > 150UL) ? (millis() - 150UL) : millis(); // estimatees when igntion happened
        fusedVelocity = currentvelocity;
        barovelocity = 0.0f;   //starts clean so it ignores noise from being on pad
        baroAccel = 0.0f;      //integrates with no decay so it drifts worst
        peakAltitude = agl;
        fallingCount = 0;
        Serial.println(" Nominal Launch , Sensors are Logging ");
      }
    }


    if (currentState != PAD_IDLE)
    {
      float aVert = az - 9.81f; // vertical velocity 
      fusedVelocity += aVert * dt; //integrates it forward 
      fusedVelocity = constrain(fusedVelocity, VEL_MIN, VEL_MAX); //backup incase ICM glitches or saturates
    }

    //                                        ALPHA-BETA BARO VELOCITY FILTER                                     //

    float timeSinceLastVel = (currentMillis - previousTime) / 1000.0f;
    if (baroOk && timeSinceLastVel >= 0.1f) // makes the filter run at 10hz (slower than the 20ms(50hz) loop so it doesnt get buried in noise)
    {
      float rawVel = (currentAltitude - previousAltitude) / timeSinceLastVel; // raw velocity is simple and very noise so needs filtering

      // Predict next state
      predictedVel = barovelocity + (baroAccel * timeSinceLastVel);

      // Calculate difference between measured and predicted
      float residual = rawVel - predictedVel;

      // Update estimates using Alpha and Beta weights
      barovelocity = predictedVel + (alpha * residual);
      baroAccel = baroAccel + (beta * residual / timeSinceLastVel); // correct step for accel at only 5% so the output isnt oscillating wildly
      
      float trust = BARO_TRUST;
      if (currentState == ASCENT && (currentMillis - launchTime) < (unsigned long)(burnTime * 1000.0f)) trust = 0.0f;
      fusedVelocity += trust * (barovelocity - fusedVelocity); // fusion step // Pulls the accelerometer-propagated estimate 35% of the way toward the barometer estimate.

      previousAltitude = currentAltitude;
      previousTime = currentMillis;
    }

    // Only runs MPC and mass calcs if the rocket is actively flying upwards.
    if (currentState == ASCENT)
    {
      //                                                   REAL TIME MASS CALC                        //

      float elapsed = (currentMillis - launchTime) / 1000.0f;
      if (elapsed < burnTime) // linear from wet mass to dry mass (obviously not linear in real life but its only 1.4s burn time)
      {
        currentMass = padMass - ((padMass - dryMass) * (elapsed / burnTime));
      }
      else
      {
        currentMass = dryMass;
      }

      // velocity test, resets falling until it is actually falling
      if (agl > peakAltitude)
      {
        peakAltitude = agl;
        fallingCount = 0;
      }
      else if (agl < peakAltitude - 1.0f)
      {
        fallingCount++;
      }

      // Check for apogee for descent
      if (peakAltitude > 50.0f && (fusedVelocity < -2.0f || fallingCount >= 5))
      {
        currentState = DESCENT;
        myservo.write(SERVO_MAX); // stowed till parachute deployment
        currentServoAngle = SERVO_MAX;
        apogeeTime = currentMillis;
        brakesDeployed = false;

        landingRefAlt = agl;
        stillSince = 0;
        Serial.println("APOGEE REACHED - DESCENT STATE ENGAGED");
      }
      else
      {
        // new burnphase check, keep airbreaks stored till burn is over
        if (elapsed >= burnTime + MPC_ARM_MARGIN_S)
        {
//                          MPC CONTROLLER                                         //
          // NEW MPC REFINEMENT AND PHYSYICS SIM (lemme cook gang)

          float rhoNow = airDensity(); // call
          rho = constrain(rhoNow, RHO_MIN, RHO_MAX); // variable based on call also validates it 3 times from the 3 density checks at the start of code 

          //ranks 41 candidates based on cost, and punishes the MPC for overshooting too much and tells it to undershoot if its going to overshoot (slam brakes)
          float bestCost = 1000000.0f; // score tracker for the 11 sims
          float bestCD = CDClean; // safety net if all 41 sims fail 
          bestApogee = agl;


          // Sims 41 different airbrake states
          for (int c = 0; c < MPC_CANDIDATES; c++)
          {
            float CDSim = CDClean + ((float)c * ((CDMax - CDClean) / (float)(MPC_CANDIDATES - 1)));
            float altSim = predictApogee(CDSim, agl, fusedVelocity, currentMass);

            // Check how close this simulation got to the target apogee
            float err = altSim - (float)apogeeTgt;
            float cost = (err > 0.0f) ? (err * overshootPenalty) : (-err);

            if (cost < bestCost)
            {
              bestCost = cost;
              bestCD = CDSim; // Saves the best CD to be used by servo
              bestApogee = altSim;
             
            }
          }
          CD = bestCD;

          //servo smoothing and limits so the servo doesnt strain itself
          int targetAngle = map((long)(CD * 10000), (long)(CDClean * 10000), (long)(CDMax * 10000), SERVO_MAX, SERVO_MIN);
          targetAngle = constrain(targetAngle, SERVO_MIN, SERVO_MAX);

          //deadband stops the servo from attempting a 5 degree or less movement
          if (abs(targetAngle - currentServoAngle) >= SERVO_DEADBAND)
          {
            if (targetAngle > currentServoAngle)
            {
              currentServoAngle += SERVO_STEP;
              if (currentServoAngle > targetAngle) currentServoAngle = targetAngle;
            }
            else if (targetAngle < currentServoAngle)
            {
              currentServoAngle -= SERVO_STEP;
              if (currentServoAngle < targetAngle) currentServoAngle = targetAngle;
            }
            myservo.write(currentServoAngle);
          }
        }
        else
        {
          // Keep airbrakes strictly closed/stowed during the motor burn phase
          currentServoAngle = SERVO_MAX;
          myservo.write(currentServoAngle);
        }
      }
    }

    if (currentState == DESCENT) // landing detection and missed logs/reads
    {
      if (!brakesDeployed && (currentMillis - apogeeTime) >= AIRBRAKE_DESCENT_DELAY_MS)
      {
        brakesDeployed = true;
        currentServoAngle = SERVO_MIN;   // 0 degrees, fully open, max drag
        myservo.write(currentServoAngle);
        Serial.println("parachute done - airbrakes to full");
      }

      float accelMagNow = sqrtf(sq(ax) + sq(ay) + sq(az));
      bool lowEnough  = (agl < LANDING_ALT_MAX);
      bool altStable  = (fabsf(agl - landingRefAlt) < LANDING_ALT_BAND);
      bool accelQuiet = (fabsf(accelMagNow - 9.81f) < LANDING_ACC_BAND);
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

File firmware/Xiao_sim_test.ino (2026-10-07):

#include <SPI.h>
#include <SD.h>

#define SEALEVELPRESSURE_PA (101325.0)

const int chipSelect = D3;
const int SD_SCK  = D8;
const int SD_MISO = D2;
const int SD_MOSI = D10;

File dataFile;

QueueHandle_t sdQueue;
TaskHandle_t sdTaskHandle;
#define LOG_BUF_LEN   256
#define LOG_QUEUE_LEN 100
char logBuffer[LOG_BUF_LEN];
bool loggingEnabled = true;
bool sdCardOk = false;
bool fileOpened = false;
const char *LOG_PATH = "/sim_flight.csv";

unsigned long previousMicros = 0;
const unsigned long INTERVAL_US = 20000UL;
unsigned long loopDtUs = 0;

enum FlightState
{
  PAD_IDLE,
  ASCENT,
  DESCENT,
  LANDED
};
FlightState currentState = PAD_IDLE;

float groundAltitude = 0.0;
float currentAltitude = 0.0;
float previousAltitude = 0.0;
unsigned long previousTime = 0;

float currentvelocity = 0.0;
float barovelocity = 0.0;
float distancetravelled = 0.0;
float predictedVel = 0.0;
float baroAccel = 0.0;
float alpha = 0.4;
float beta = 0.05;
float fusedVelocity = 0.0;
const float BARO_TRUST = 0.35;

const float RHO_MIN = 0.6;
const float RHO_MAX = 1.4;
const float VEL_MIN = -150.0;
const float VEL_MAX = 200.0;

int fallingCount = 0;
float peakAltitude = 0.0;

unsigned long stillSince = 0;
volatile bool closeRequested = false;
unsigned int droppedLogs = 0;
unsigned int missedBaro = 0;

float landingRefAlt = 0.0;
const float LANDING_ALT_MAX  = 25.0;
const float LANDING_ALT_BAND = 3.0;
const float LANDING_ACC_BAND = 1.5;

unsigned long launchTime = 0;
float padMass = 0.7293;
float currentMass = 0.789;
float dryMass = 0.7293;
float burnTime = 1.4;

int currentServoAngle = 126;
const int SERVO_MIN = 0;
const int SERVO_MAX = 126;
const int SERVO_STEP = 3;
const int SERVO_DEADBAND = 5;

float area = 0.0019635;
float rho = 1.225;
float CDClean = 0.4724;
float CDMax   = 0.8776;
float CD = CDClean;
int apogeeTgt = 530;
const float overshootPenalty = 1.25;
const float MPC_ARM_MARGIN_S = 0.1;

const unsigned long AIRBRAKE_DESCENT_DELAY_MS = 3000UL;
unsigned long apogeeTime = 0;
bool brakesDeployed = false;

#define MPC_CANDIDATES 41
float bestApogee = 0.0;

float accelScale = 1.0f;

const float SIM_PAD_ALT   = 103.0f;
const float SIM_PAD_HOLD  = 3.0f;
const float SIM_BURN      = 1.4f;
const float SIM_WET       = 0.789f;
const float SIM_DRY       = 0.7293f;
const float SIM_AREA      = 0.0019635f;
const float SIM_CHUTE_CDA = 0.060f;
const float SIM_CHUTE_DELAY = 1.0f;
const float SIM_BARO_NOISE = 3.0f;
const float SIM_ACC_NOISE  = 0.12f;
const float SIM_TIMEOUT_S  = 240.0f;
const int   SIM_BARO_MISS_ODDS = 500;

float simTime = 0.0f;
float simAgl = 0.0f;
float simVel = 0.0f;
float simAccelVert = 0.0f;
float simPeakAgl = 0.0f;
float simApogeeTime = 0.0f;
bool  simLiftoff = false;
bool  simApogee = false;
bool  simChuteOut = false;
bool  simTouchdown = false;
bool  simFinished = false;

float simPressure = 101325.0f;
float simTemperature = 15.0f;
float simAx = 0.0f;
float simAy = 0.0f;
float simAz = 9.81f;
float simGx = 0.0f;
float simGy = 0.0f;
float simGz = 0.0f;
float simMx = 22.0f;
float simMy = -3.0f;
float simMz = 41.0f;
bool  simBaroOk = true;

float maxFusedVel = 0.0f;
int   minServoSeen = 126;
float simBurnoutVel = 0.0f;
float simBurnoutAlt = 0.0f;
unsigned long simStartMillis = 0;

void logToSDTask(void *pvParameters);

bool sdInit()
{
  pinMode(chipSelect, OUTPUT);
  digitalWrite(chipSelect, HIGH);
  SPI.begin(SD_SCK, SD_MISO, SD_MOSI, chipSelect);
  delay(50);

  const uint32_t speeds[3] = {400000UL, 1000000UL, 4000000UL};
  for (int attempt = 0; attempt < 9; attempt++)
  {
    uint32_t sp = speeds[attempt % 3];
    Serial.print("SD init attempt ");
    Serial.print(attempt + 1);
    Serial.print(" at ");
    Serial.print(sp);
    Serial.print(" Hz ... ");
    if (SD.begin(chipSelect, SPI, sp))
    {
      Serial.println("OK");
      uint8_t ct = SD.cardType();
      Serial.print("card type: ");
      if (ct == CARD_NONE) Serial.println("NONE");
      else if (ct == CARD_MMC) Serial.println("MMC");
      else if (ct == CARD_SD) Serial.println("SDSC");
      else if (ct == CARD_SDHC) Serial.println("SDHC");
      else Serial.println("UNKNOWN");
      Serial.print("card size (MB): ");
      Serial.println((unsigned long)(SD.cardSize() / (1024ULL * 1024ULL)));
      return (ct != CARD_NONE);
    }
    Serial.println("fail");
    SD.end();
    delay(300);
  }
  return false;
}

float pressurePa()
{
  return simPressure;
}

float altitudeFromPa()
{
  return 44330.0f * (1.0f - powf(pressurePa() / (float)SEALEVELPRESSURE_PA, 0.1903f));
}

float airDensity()
{
  return pressurePa() / (287.05f * (simTemperature + 273.15f));
}

float predictApogee(float cdSim, float alt0, float v0, float mass)
{
  if (v0 <= 0.0f) return alt0;
  float k = (rho * cdSim * area) / (2.0f * mass);
  if (k < 1e-9f) return alt0;
  float h = (1.0f / (2.0f * k)) * logf(1.0f + (k * v0 * v0) / 9.81f);
  float rhoMid = rho * (1.0f - (0.5f * h) / 8500.0f);
  if (rhoMid < RHO_MIN) rhoMid = RHO_MIN;
  k = (rhoMid * cdSim * area) / (2.0f * mass);
  if (k < 1e-9f) return alt0;
  h = (1.0f / (2.0f * k)) * logf(1.0f + (k * v0 * v0) / 9.81f);
  return alt0 + h;
}

float simNoise(float amp)
{
  return ((float)random(-1000, 1001) / 1000.0f) * amp;
}

float simThrust(float t)
{
  static const float tt[7] = {0.00f, 0.05f, 0.20f, 0.60f, 1.00f, 1.30f, 1.40f};
  static const float ff[7] = {0.00f, 95.0f, 86.0f, 80.0f, 74.0f, 60.0f, 0.00f};
  if (t <= 0.0f || t >= SIM_BURN) return 0.0f;
  for (int i = 0; i < 6; i++)
  {
    if (t >= tt[i] && t <= tt[i + 1])
    {
      float f = (t - tt[i]) / (tt[i + 1] - tt[i]);
      return ff[i] + f * (ff[i + 1] - ff[i]);
    }
  }
  return 0.0f;
}

float simCdFromServo()
{
  float f = (float)(SERVO_MAX - currentServoAngle) / (float)(SERVO_MAX - SERVO_MIN);
  if (f < 0.0f) f = 0.0f;
  if (f > 1.0f) f = 1.0f;
  return CDClean + f * (CDMax - CDClean);
}

float simPressureFromAlt(float altM)
{
  float ratio = 1.0f - (altM / 44330.0f);
  if (ratio < 0.0001f) ratio = 0.0001f;
  return (float)SEALEVELPRESSURE_PA * powf(ratio, 1.0f / 0.1903f);
}

void simSensors()
{
  float trueAlt = SIM_PAD_ALT + simAgl;
  simPressure = simPressureFromAlt(trueAlt) + simNoise(SIM_BARO_NOISE);
  simTemperature = 15.0f - 0.0065f * trueAlt + simNoise(0.05f);

  simAz = simAccelVert + 9.81f + simNoise(SIM_ACC_NOISE);
  simAx = simNoise(SIM_ACC_NOISE);
  simAy = simNoise(SIM_ACC_NOISE);

  if (simLiftoff && !simTouchdown)
  {
    simAx += simNoise(0.6f);
    simAy += simNoise(0.6f);
    simGx = simNoise(0.35f);
    simGy = simNoise(0.35f);
    simGz = simChuteOut ? simNoise(2.5f) : (2.2f + simNoise(0.4f));
  }
  else
  {
    simGx = simNoise(0.01f);
    simGy = simNoise(0.01f);
    simGz = simNoise(0.01f);
  }

  simMx = 22.0f + simNoise(0.8f);
  simMy = -3.0f + simNoise(0.8f);
  simMz = 41.0f + simNoise(0.8f);

  simBaroOk = (random(0, SIM_BARO_MISS_ODDS) != 0);
}
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

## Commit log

2026-10-07 initial commit - icarus avionics, cfd and flight sim
    flight computer and airbrake control for icarus, our entry to the UKSEDS
    national rocketry championship at coventry.
    firmware for the XIAO ESP32-C3 (50hz loop, mpc that sweeps 41 drag candidates
    and solves for apogee in closed form), the two openfoam cases i ran to get the
    clean and deployed drag coefficients it uses, renders of the board, the
    openrocket model and the matlab script for reading logs back.
    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
    [SRocketMesh.stl]
2026-10-08 Changes to Xiao ESP32-C3 code
